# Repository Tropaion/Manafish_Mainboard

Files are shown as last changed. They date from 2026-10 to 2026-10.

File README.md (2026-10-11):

# Manafish Mainboard

The Manafish Mainboard is the main electronics board of the
[Manafish ROV](https://github.com/manafishrov). It replaces the Raspberry Pi 3B,
the USB-connected Raspberry Pi Pico and the wiring between them with one board:

- a **Raspberry Pi Compute Module 5** for the tether network, the camera and
  the vehicle firmware ([manafishrov/firmware](https://github.com/manafishrov/firmware)),
- an **RP2354A** microcontroller that drives the eight thrusters over
  bidirectional DShot ([manafishrov/mcu-firmware](https://github.com/manafishrov/mcu-firmware)),
- two camera connectors, Ethernet with PoE-capable magnetics, a magnet power
  switch input, and the on-board sensors.

> [!WARNING]
> Work in progress. The schematic and the 4-layer PCB layout are drawn, but no
> board has been built or tested. Don't manufacture from this repository yet.

## Overview
View the latest [KiCad Design](https://kicanvas.org/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).

```mermaid
flowchart LR
  tether["Tether (Ethernet)"] --> magjack["MagJack + ESD"]
  magjack -->|4 pairs| cm5["Compute Module 5"]
  magjack -.->|center taps| poe["PoE module IC5 (Ag59824, 24 V)"]
  cm5 -->|MIPI0| cam["Camera connector J5"]
  cm5 -->|MIPI1| cam2["Camera connector J11"]
  cm5 -->|"USB 2.0 (data only)"| service["USB-C service port J8"]
  cm5 -->|I2C1| sensors["BMI270, SHT45, MS5837 connector"]
  cm5 -->|"USB 2.0 (USB3-1 port)"| mcu["RP2354A"]
  cm5 -->|"GPIO24 RUN, GPIO25 BOOTSEL"| mcu
  mcu -->|GP6-GP9| escA["ESC A, 4-in-1 (AM32)"]
  mcu -->|GP18-GP21| escB["ESC B, 4-in-1 (AM32)"]
  poe --> chg["Charger IC8 (LTC4162-L)"]
  bat["Battery J6 (5S)"] <--> chg
  chg -->|VSYS| buck["5 V buck IC9 (TPSM53604)"]
  mag["Magnet switch board J12"] -->|MAG_ON| lsw
  buck -->|5 V always on| lsw["Load switch IC15 (TPS22965)"]
  lsw -->|5 V| cm5
```

## Schematic sheets

| Sheet | File | Contents | Origin |
| --- | --- | --- | --- |
| Manafish (top level) | `manafish.kicad_sch` | Sheet hierarchy, battery input J6, USB-C service port J8, magnet switch connector J12 | Original; USB-C port adapted from the CM5 IO Board |
| Raspberry Pi Compute Module 5 | `cm5.kicad_sch` | CM5 module connectors, boot and EEPROM jumper header J7 | Adapted from the CM5 IO Board |
| Camera Serial Interface | `csi.kicad_sch` | 22-pin MIPI camera connectors J5 (MIPI0) and J11 (MIPI1), 3.3 V from CM5_3.3V | Adapted from the CM5 IO Board |
| Ethernet | `ethernet.kicad_sch` | MagJack IC3 (YAGEO JXF0-1012NL, 4-pair PoE center taps), ESD protection IC1/IC2, link LEDs | Adapted from the CM5 IO Board |
| Serial Peripherals | `serial_peripherals.kicad_sch` | BMI270 IMU (SPI to the RP2354A), SHT45 humidity and temperature sensor, WSEN-PADS pressure sensor IC10, MS5837 connector | Original |
| RP2354A | `rp2354a.kicad_sch` | RP2354A with core regulator, USB, SWD connector J2, ESC connectors J3/J4 | Original, following *Hardware design with RP2350* |
| Power Management | `power_management.kicad_sch` | PoE bridges D2–D5, PoE module IC5, LTC4162-L charger IC8, 5 V buck IC9, load switch IC15 | Original |

"Adapted from the CM5 IO Board" means the sheet started from Raspberry Pi's
reference design; see [Origin and attribution](#origin-and-attribution).

## Interfaces

Compute Module 5:

| Signal | CM5 pin | Connects to |
| --- | --- | --- |
| Ethernet pairs 0–3 | 3–12 | MagJack IC3 |
| GPIO2 / GPIO3 (I2C1) | 58 / 56 | BMI270, SHT45, MS5837 connector |
| GPIO24 | 45 | RP2354A `RUN` |
| GPIO25 | 41 | RP2354A `QSPI_SS` (BOOTSEL) |
| USB3-1 D+ / D− (USB 2.0 pair) | 163 / 165 | RP2354A USB |
| MIPI0 data and clock lanes | 115–141 | Camera connector J5 |
| SDA0 / SCL0 | 82 / 80 | Camera connector J5 |
| CAM_GPIO0 / CAM_GPIO1 | 97 / 100 | Camera connector J5 |
| MIPI1 data and clock lanes | 175–196 | Camera connector J11 |
| ID_SD / ID_SC (I2C, 2.2 kΩ pull-ups R4/R5) | 36 / 35 | Camera connector J11 |
| GPIO14 / GPIO15 | 55 / 51 | Camera connector J11 pins 17 / 18 (CAM1_GPIO0 / CAM1_GPIO1) |
| USB_P / USB_N (USB 2.0) | 105 / 103 | USB-C service port J8, data only |
| nRPIBOOT, EEPROM_nWP, SYNC_OUT, USB_OTG_ID, PMIC_ENABLE, PWR_BUT | 93, 20, 18, 101, 99, 92 | Jumper header J7 |
| GPIO_VREF | 78 | CM5_3.3V (3.3 V GPIO levels) |
| +5 V input | 77–87 | Power management, through load switch IC15 |
| CM5_3.3V output | 84 / 86 | RP2354A and sensors |

RP2354A (QFN-60):

| Signal | RP2354A pin | Connects to |
| --- | --- | --- |
| GP6–GP9 | 9, 10, 12, 13 | ESC A connector J3 |
| GP18–GP21 | 29, 31, 32, 33 | ESC B connector J4 |
| USB_DP / USB_DM | 52 / 51 | CM5 USB3-1, 27 Ω in series |
| RUN | 26 | CM5 GPIO24 |
| QSPI_SS | 60 | CM5 GPIO25 |
| SWCLK / SWDIO | 24 / 25 | Debug connector J2 |
| XIN / XOUT | 21 / 22 | 12 MHz crystal Y1 (ABM8-272-T3) |

I2C devices on the CM5's I2C1 bus:

| Device | Address | Notes |
| --- | --- | --- |
| BMI270 IMU | `0x68` | `0x69` if SDO is pulled to VDDIO |
| SHT45-AD1F (with PTFE membrane) | `0x44` | |
| MS5837-30BA pressure sensor (external module) | `0x76` | Fixed address |

## Repository layout

```text
hardware/
├── manafish.kicad_pro      KiCad project
├── *.kicad_sch             schematic sheets
├── manafish.kicad_pcb      PCB, 4 layers
├── manafish.kicad_dru      custom DRC rules for the PoE isolation barriers
├── sym-lib-table           project symbol libraries
├── fp-lib-table            project footprint libraries
└── custom_components/
    ├── symbols/            CM5IO, BMI270, SHT45, ABM8-272-T3, Silvertel, V6K100DUHM3, FDMC8327L, LTC4162, YAGEO symbols
    ├── footprints/         CM5IO, BMI270, SHT45, ABM8-272-T3, RP2350_Minimal, Silvertel, V6K100DUHM3, FDMC86139P, LTC4162, YAGEO footprints
    └── 3d/                 STEP models
```

## PCB

`manafish.kicad_pcb` is a 70 × 100 mm, 4-layer board. It sits centred on the
axis of a tube with a 74 mm inner diameter, so a part at lateral distance *d*
from the axis may stand at most √(37² − *d*²) − 0.8 mm above the board surface.
Every part fits, checked against the 3D models. The tightest are the USB-C port
J8 (1.8 mm to the tube wall) and the SWD connector J2 (2.3 mm).

### Stackup

JLCPCB JLC04161H-7628, 1.6 mm, ENIG finish:

| Layer | Thickness | Use |
| --- | --- | --- |
| F.Cu | 35 µm | Parts, signals, GND and power pours |
| Prepreg 7628 | 0.21 mm, εr 4.4 | |
| In1.Cu | 15 µm | Solid GND reference, no tracks |
| Core | 1.065 mm, εr 4.6 | |
| In2.Cu | 15 µm | GND, power pours (VSYS, +5 V, 3V3), signals |
| Prepreg 7628 | 0.21 mm, εr 4.4 | |
| B.Cu | 35 µm | PoE module IC5, PoE input, signals, GND and 24 V pours |

Order the board with impedance control:

| Net class | Nets | Width / gap | Target |
| --- | --- | --- | --- |
| `DP100` | Ethernet `TRD*`, camera `DPHY0_*` and `DPHY1_*` | 0.21 / 0.19 mm on F.Cu and B.Cu | 100 Ω differential |
| `USB90` | `USB2_*`, RP2354A `USB_D*` | 0.24 / 0.15 mm on F.Cu | 90 Ω differential |

Inside the CM5 connector pin fields the pairs neck down to 0.127 mm for at most
1.6 mm. Pours keep 0.3 mm from the pairs everywhere.

### PoE isolation

The PoE input side (the `Primary` net class: center taps, bridges, IC5 input,
TYP outputs) is isolated from the rest of the board. `manafish.kicad_dru`
enforces:

- 2.0 mm from primary copper to any other net, on every layer and from every
  hole. The only exception is between the pads of each Y-capacitor
  (C21, C24).
- A 3.0 mm warning tier, the Silvertel guideline. 21 warnings remain, all
  between 2.0 and 3.0 mm:
  - the MagJack's own center-tap pads to its shield pins (2.14 mm) and the VC3
    track next to the shield (2.02 mm);
  - the Y-capacitors' own pads (2.7 mm) and C21's GND pad to the ferrite beads
    (2.26 mm);
  - the RP2354A decoupling GND vias next to the ferrite-bead column (2.38 mm);
  - R23 next to IC5's VIN+ pad (2.8 mm).
- Under IC5's primary half (`PRI_ISLAND_U5`), no vias of other nets and no
  other copper on B.Cu or In2. The module's isolation barrier strip stays
  empty on B.Cu and In2.

The inner layers are voided 2 mm around primary copper on the next outer layer
(In2 under primary B.Cu, In1 under primary F.Cu), and In1 stays clear of the
front edge where the VC1 track runs on In2. Only IC5, the optocouplers IC6/IC7 and
the Y-capacitors C21/C24 cross the barrier.

Connector A of the CM5 lies inside the island, so 16 of its GND pins have no
via to the GND planes. They connect through the CM5's own ground: the footprint
`Module1` declares all its GND pads as one jumper pad group.

### Assembly

- IC5 (Ag59824-LPB) is on the bottom and must never pass through reflow hanging
  upside down. Reflow the top side first, then the bottom side with IC5 upright,
  or fit IC5 afterwards with hot air. Glue L2 (1.0–1.6 g) and IC9 before the
  second pass.
- IC5 reflow profile: peak 230–245 °C, 30–90 s above 217 °C, soak 150–180 °C for
  30–90 s, ramp up at most 3 °C/s and down at most 6 °C/s. No wave solder on the
  IC5 side.
- Solder the through-hole parts IC3, J6, J7 and C20 by hand after both reflow
  passes.
- Fit the CM5 with M2.5 screws from below (head at most 4.5 mm across) and the
  nuts on the CM5 side. A nut under the board would hit C20.

The same notes are on the board's User.Comments layer, which isn't part of the
Gerbers: copy them into the order remarks for the assembler.

### Testing the isolation

Use the 1500 V 10/700 µs impulse test only, at normal air pressure. Don't run
a 1500 Vrms or 2250 Vdc hipot: the Ag59824 is rated only for the impulse
test, and 2250 V exceeds the Y-capacitors' 2 kV rating. Afterwards the primary
side must measure at least 2 MΩ to GND at 500 Vdc.

## Flashing the Compute Module

The USB-C port J8 carries data only. Its VBUS isn't connected, so the board
needs its normal supply while you flash it.

1. Power the board.
2. Fit a jumper on J7 pins 1–2 (`nRPIBOOT`).
3. Connect J8 to a computer and run
   [`rpiboot`](https://github.com/raspberrypi/usbboot)
   `-d mass-storage-gadget64`. The eMMC appears as a USB drive.
4. Write the image, then remove the jumper.

Set `PSU_MAX_CURRENT=5000` in the bootloader EEPROM configuration. The CM5
isn't powered over USB-C, so it can't detect the supply's capability itself.

Jumper header J7:

| Pins | Signal | Fitted means |
| --- | --- | --- |
| 1–2 | `nRPIBOOT` | Boot from USB, for flashing |
| 3–4 | `EEPROM_nWP` | Bootloader EEPROM write-protected; blocks EEPROM updates |
| 5–6 | `SYNC_OUT` | Ethernet timing output; never fit a jumper |
| 9–10 | `USB_OTG_ID` | USB 2.0 port in host mode; leave open for flashing |
| 11–12 | `PMIC_ENABLE` | CM5 switched off |
| 13–14 | `PWR_BUT` | For a push button: short press shuts down or wakes, holding over 5 s forces power-off |

## Opening the project

1. Install [KiCad](https://www.kicad.org/) 10.0 or newer. The files are saved
   in the KiCad 10 format and won't open in older versions.
2. Open `hardware/manafish.kicad_pro`. The project libraries in
   `custom_components/` are registered in `sym-lib-table` and `fp-lib-table`;
   everything else comes from KiCad's standard libraries.

Datasheets aren't stored in the repository. Use the links below.

## Datasheets

- [Raspberry Pi Compute Module 5 datasheet](https://datasheets.raspberrypi.com/cm5/cm5-datasheet.pdf)
- [Compute Module 5 IO Board datasheet](https://datasheets.raspberrypi.com/cm5/cm5io-datasheet.pdf)
- [RP2350 datasheet](https://datasheets.raspberrypi.com/rp2350/rp2350-datasheet.pdf)
- [Hardware design with RP2350](https://datasheets.raspberrypi.com/rp2350/hardware-design-with-rp2350.pdf)
- [RP2350 product brief](https://datasheets.raspberrypi.com/rp2350/rp2350-product-brief.pdf)
- [Bosch BMI270 datasheet](https://www.bosch-sensortec.com/media/boschsensortec/downloads/datasheets/bst-bmi270-ds000.pdf)
- [Sensirion SHT45 product page and datasheet](https://sensirion.com/products/catalog/SHT45)
- [Silvertel Ag5700-LPB (Ag5724-LPB) PoE module datasheet](https://silvertel.com/images/datasheets/Ag5700LPB-datasheet-minature%20IEEE802_3At%2024W%20power-over-ethernet%20module.pdf)
- [Silvertel Ag59800 (Ag59824-LPB) PoE++ module datasheet](https://silvertel.com/images/datasheets/Ag59800-LPB%20-datasheet-high%20efficiency%20SMT%20IEEE802_3BT%20100W%20power-over-ethernet%20module.pdf)
- [Vishay V6K100DU dual Schottky diode datasheet](https://www.vishay.com/docs/87418/v6k100du.pdf)
- [Analog Devices LTC4162-L battery charger datasheet](https://www.analog.com/media/en/technical-documentation/data-sheets/LTC4162-L.pdf)
- [YAGEO (Pulse) JXF0-xx12NL MagJack datasheet J520](https://www.yageogroup.com/content/datasheet/asset/file/DATASHEET_J520)

## Related repositories

- [manafishrov/firmware](https://github.com/manafishrov/firmware): vehicle
  firmware running on the Compute Module
- [manafishrov/mcu-firmware](https://github.com/manafishrov/mcu-firmware):
  thruster firmware running on the RP2354A (Pico 2 build)
- [manafishrov/esc-firmware](https://github.com/manafishrov/esc-firmware):
  AM32 firmware for the ESCs

## Origin and attribution

This board builds on the **Raspberry Pi Compute Module 5 IO Board (CM5IO)**
reference design by Raspberry Pi Ltd.

- **Source:** *CM5 IO Board, revision 2, KiCad files* (Raspberry Pi document
  RP-008099-DD-1), downloaded from the
  [Raspberry Pi Product Information Portal](https://pip.raspberrypi.com/categories/1098-design-files).
  The original files carry the notice "Copyright © 2024 Raspberry Pi Ltd."
- **Copied unchanged:** the symbol library
  `custom_components/symbols/CM5IO.kicad_sym`, all footprints in
  `custom_components/footprints/CM5IO.pretty/`, and eight 3D models in
  `custom_components/3d/`.
- **Adapted:** the circuits in `cm5.kicad_sch`, `csi.kicad_sch` and
  `ethernet.kicad_sch`, including the boot and EEPROM jumper header J7, and
  the USB-C service port J8 in `manafish.kicad_sch`.
- **Terms:** the CM5 IO Board datasheet says the design files "can be used in
  your own reference designs", and Raspberry Pi grants permission to use its
  resources "solely in conjunction with the Raspberry Pi products". These files
  and the parts derived from them remain © Raspberry Pi Ltd under those terms.
  They are **not** covered by this repository's license.

The RP2354A circuit follows Raspberry Pi's
[*Hardware design with RP2350*](https://datasheets.raspberrypi.com/rp2350/hardware-design-with-rp2350.pdf)
(RP-008280-DS). The footprints for the core regulator inductor L1 and the SWD
connector J2 come from Raspberry Pi's RP2350A minimal design, published under
the MIT license.

Raspberry Pi is a trademark of Raspberry Pi Ltd. This project is not affiliated
with or endorsed by Raspberry Pi Ltd.

[NOTICE.md](NOTICE.md) lists every third-party file and its terms.

## License

The original work in this repository is licensed under the GNU Affero General
Public License v3.0 or later; see [LICENSE](LICENSE). Third-party files keep
their own terms, listed in [NOTICE.md](NOTICE.md).

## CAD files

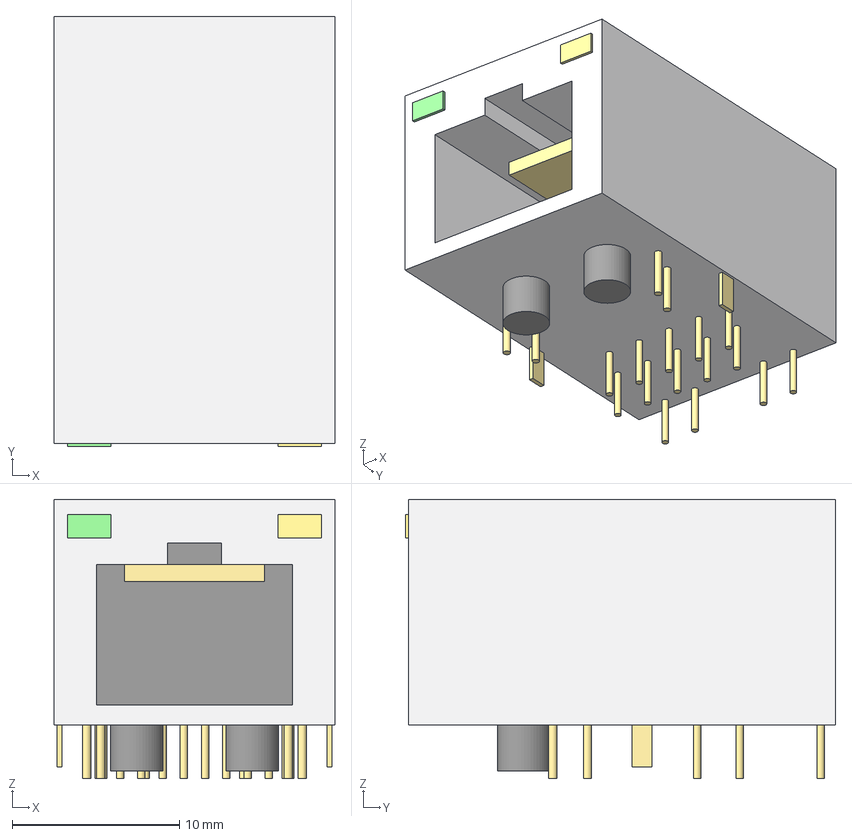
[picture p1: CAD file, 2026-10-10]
hardware/custom_components/3d/JXF0-1012NL.step
16.8 x 25.7 x 16.7 mm
shield
socket
contacts
led_green
led_yellow
pin0
pin1
pin2
pin3
pin4
pin5
pin6
pin7
pin8
pin9
pin10
pin11
pin12
pin13
pin14
pin15
pin16
pin17
pin18
pin19
peg0
peg1

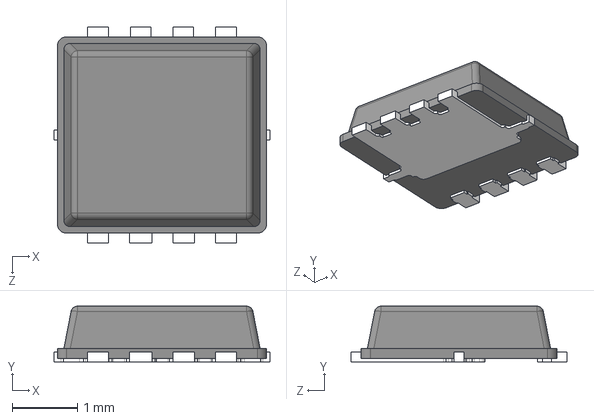
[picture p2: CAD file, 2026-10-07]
hardware/custom_components/3d/FDMC8327L.stp
3.30 x 0.85 x 3.30 mm

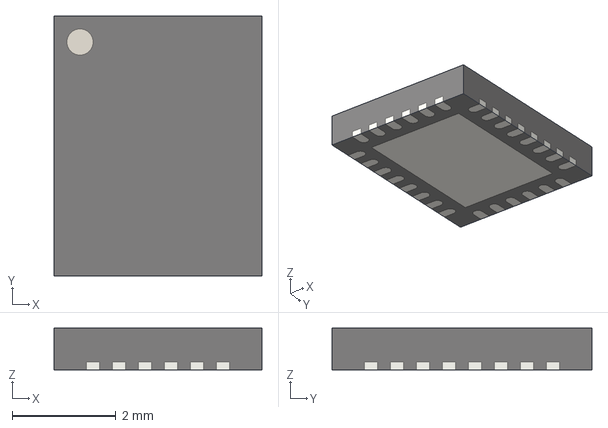
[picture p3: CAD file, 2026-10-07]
hardware/custom_components/3d/QFN-28-1EP_4x5mm_P0.5mm_EP2.65x3.65mm.step
4.00 x 5.00 x 0.8 mm

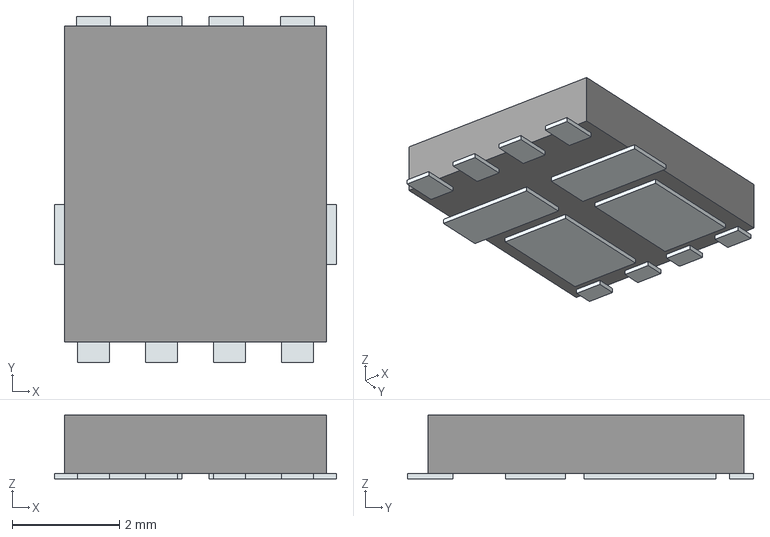
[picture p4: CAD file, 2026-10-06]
hardware/custom_components/3d/V6K100DUHM3_H.stp
5.27 x 6.46 x 1.19 mm
Pins

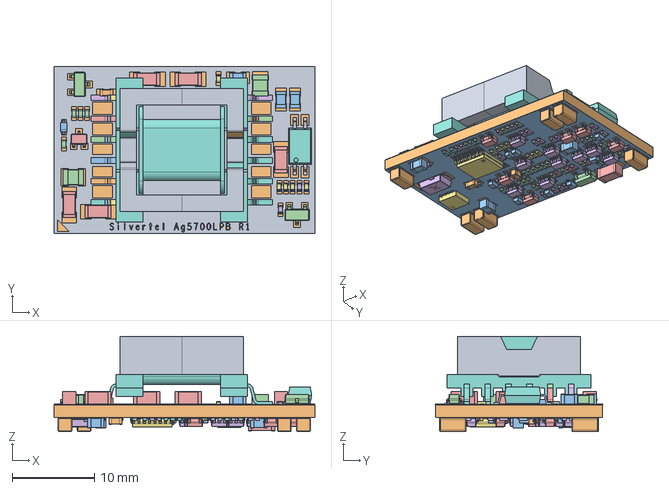
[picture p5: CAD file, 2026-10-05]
hardware/custom_components/3d/AG5700.step
31.7 x 20.3 x 11.6 mm

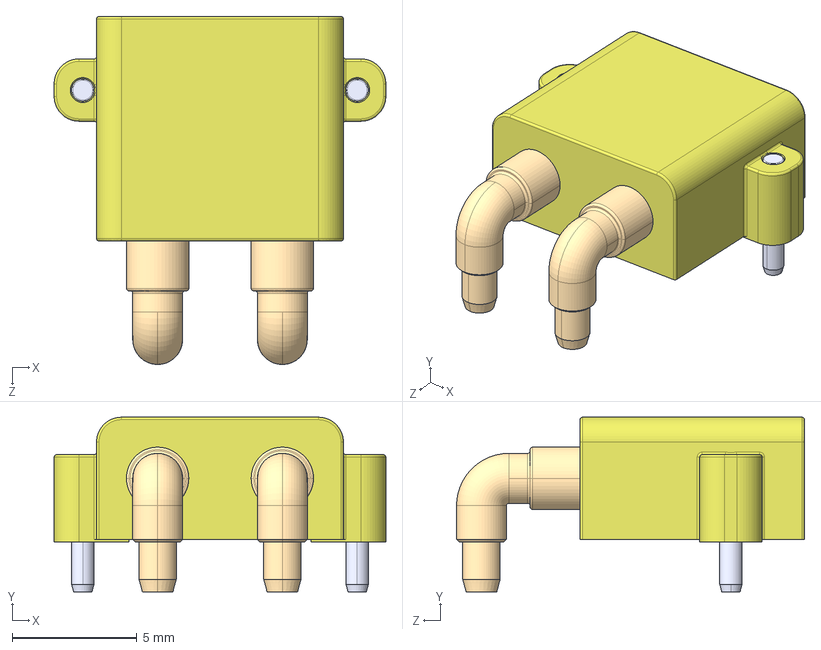
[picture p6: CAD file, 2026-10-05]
hardware/custom_components/3d/AMASS_XT30PW-M.step
13.3 x 7.00 x 14.0 mm

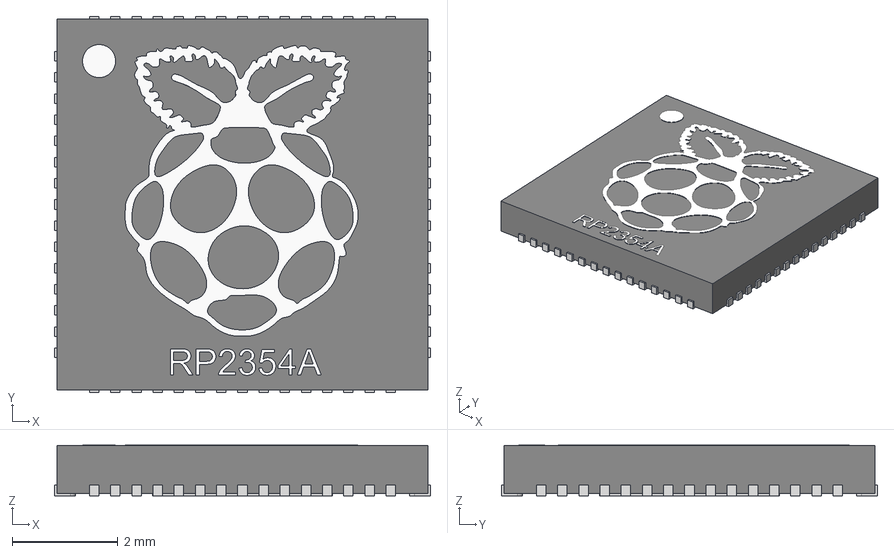
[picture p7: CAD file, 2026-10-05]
hardware/custom_components/3d/RP2354A.stp
7.10 x 7.10 x 0.96 mm

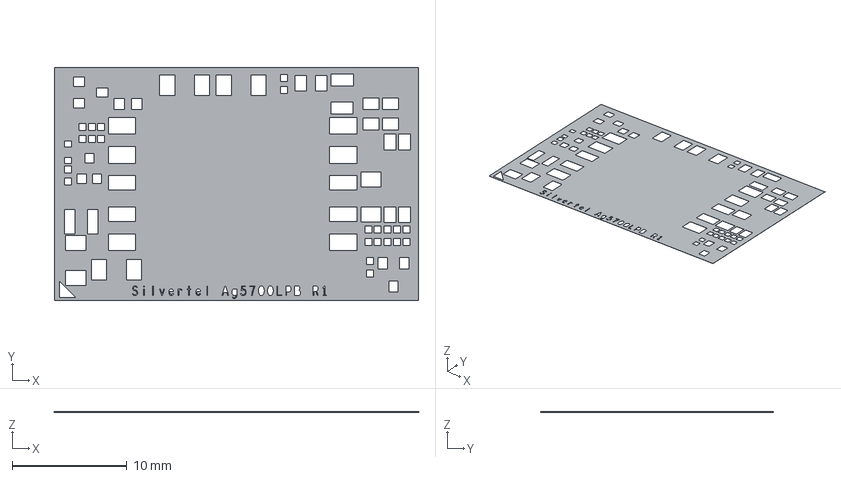
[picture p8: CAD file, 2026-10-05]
hardware/custom_components/3d/Ag5700_detailed.step
31.7 x 20.3 x 0.0127 mm

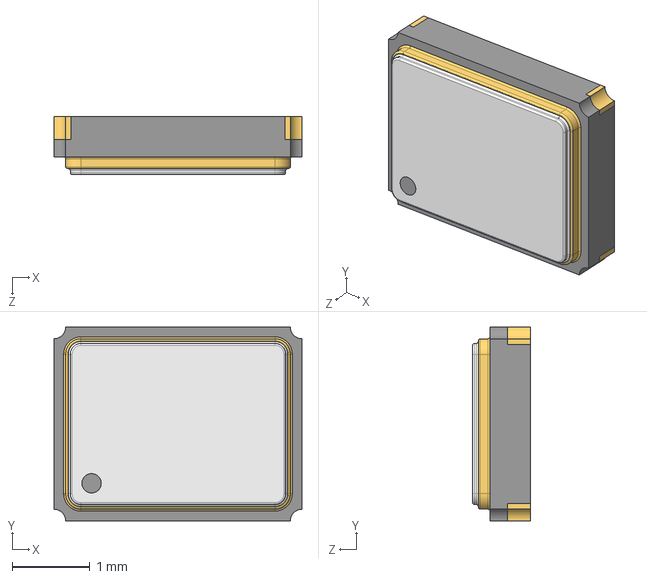
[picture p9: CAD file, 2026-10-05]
hardware/custom_components/3d/ABM8-272-T3.stp
3.20 x 2.50 x 0.75 mm

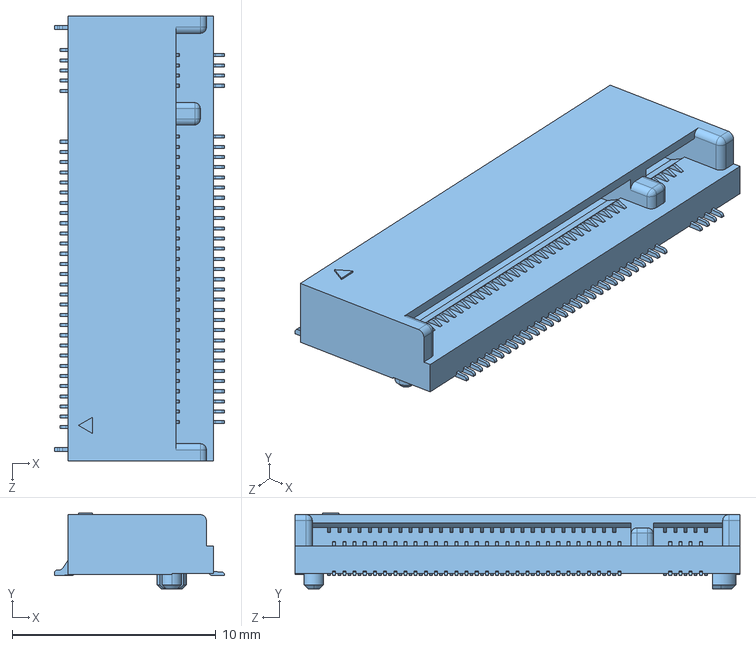
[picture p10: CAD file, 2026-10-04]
hardware/custom_components/3d/MTSSD03-67MSW337.STEP
8.37 x 3.73 x 21.9 mm

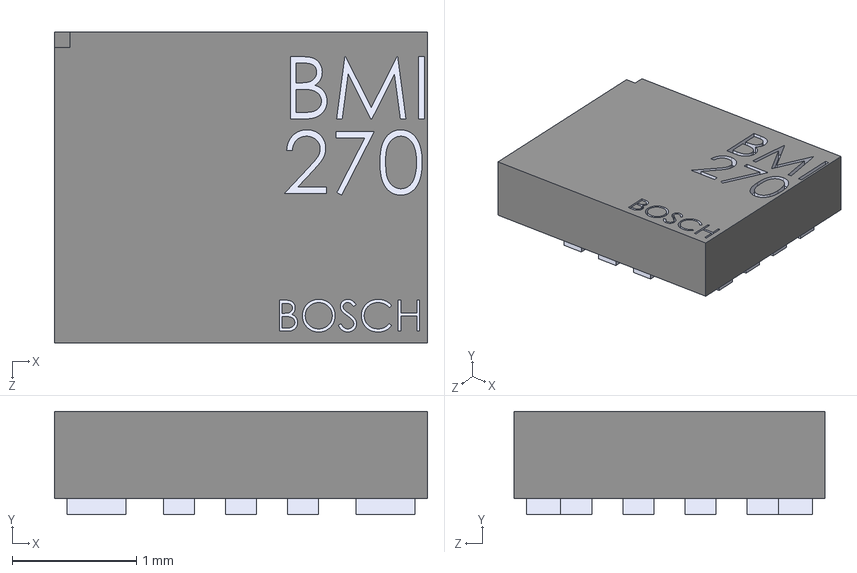
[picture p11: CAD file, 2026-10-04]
hardware/custom_components/3d/BMI270.stp
3.00 x 0.83 x 2.50 mm

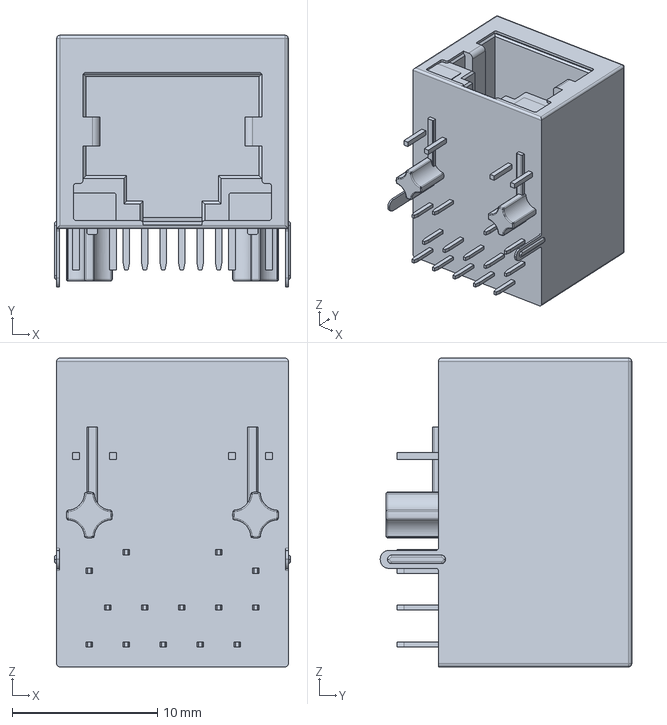
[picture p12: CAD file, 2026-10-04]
hardware/custom_components/3d/TRJG0926HENL .stp
16.2 x 17.3 x 21.2 mm

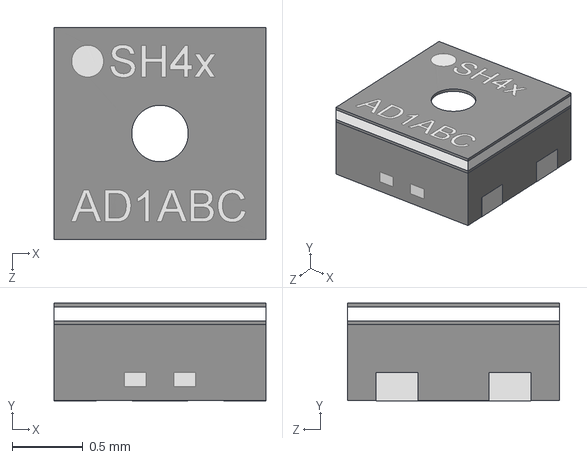
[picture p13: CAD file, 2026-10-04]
hardware/custom_components/3d/SHT45-AD1F-R2.stp
1.50 x 0.691 x 1.50 mm

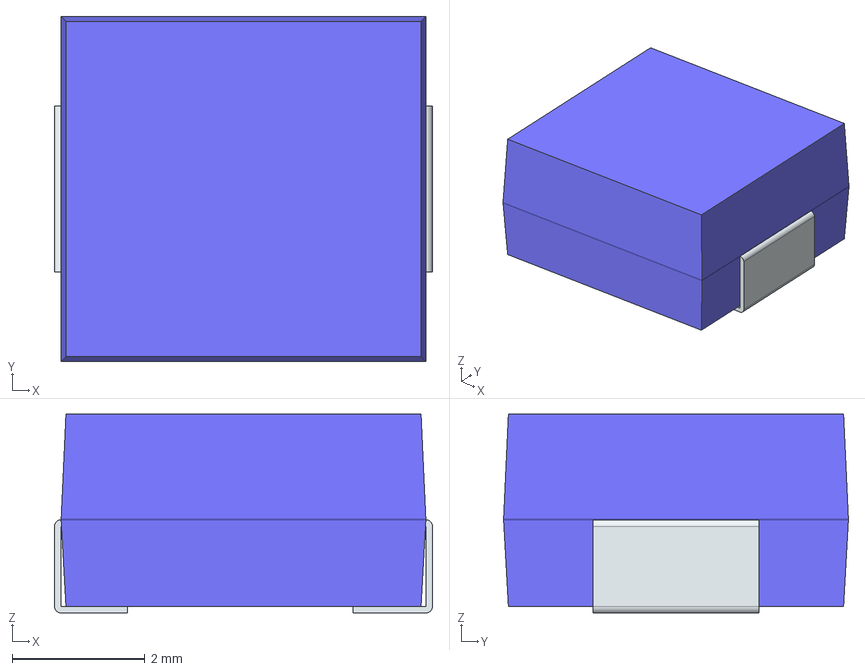
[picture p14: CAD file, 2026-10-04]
hardware/custom_components/3d/SRP5030CC.stp
5.70 x 5.20 x 3.00 mm
FilletPin1
FilletPin2

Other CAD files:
hardware/custom_components/3d/FH12-22S-0.5SH.stp
hardware/custom_components/3d/BM04B-SRSS-TB.STEP
hardware/custom_components/3d/CM5R5.step
hardware/custom_components/3d/AG59800-LPB.step
hardware/custom_components/3d/10164227-1001a1rlf.stp
hardware/custom_components/3d/471511051.stp

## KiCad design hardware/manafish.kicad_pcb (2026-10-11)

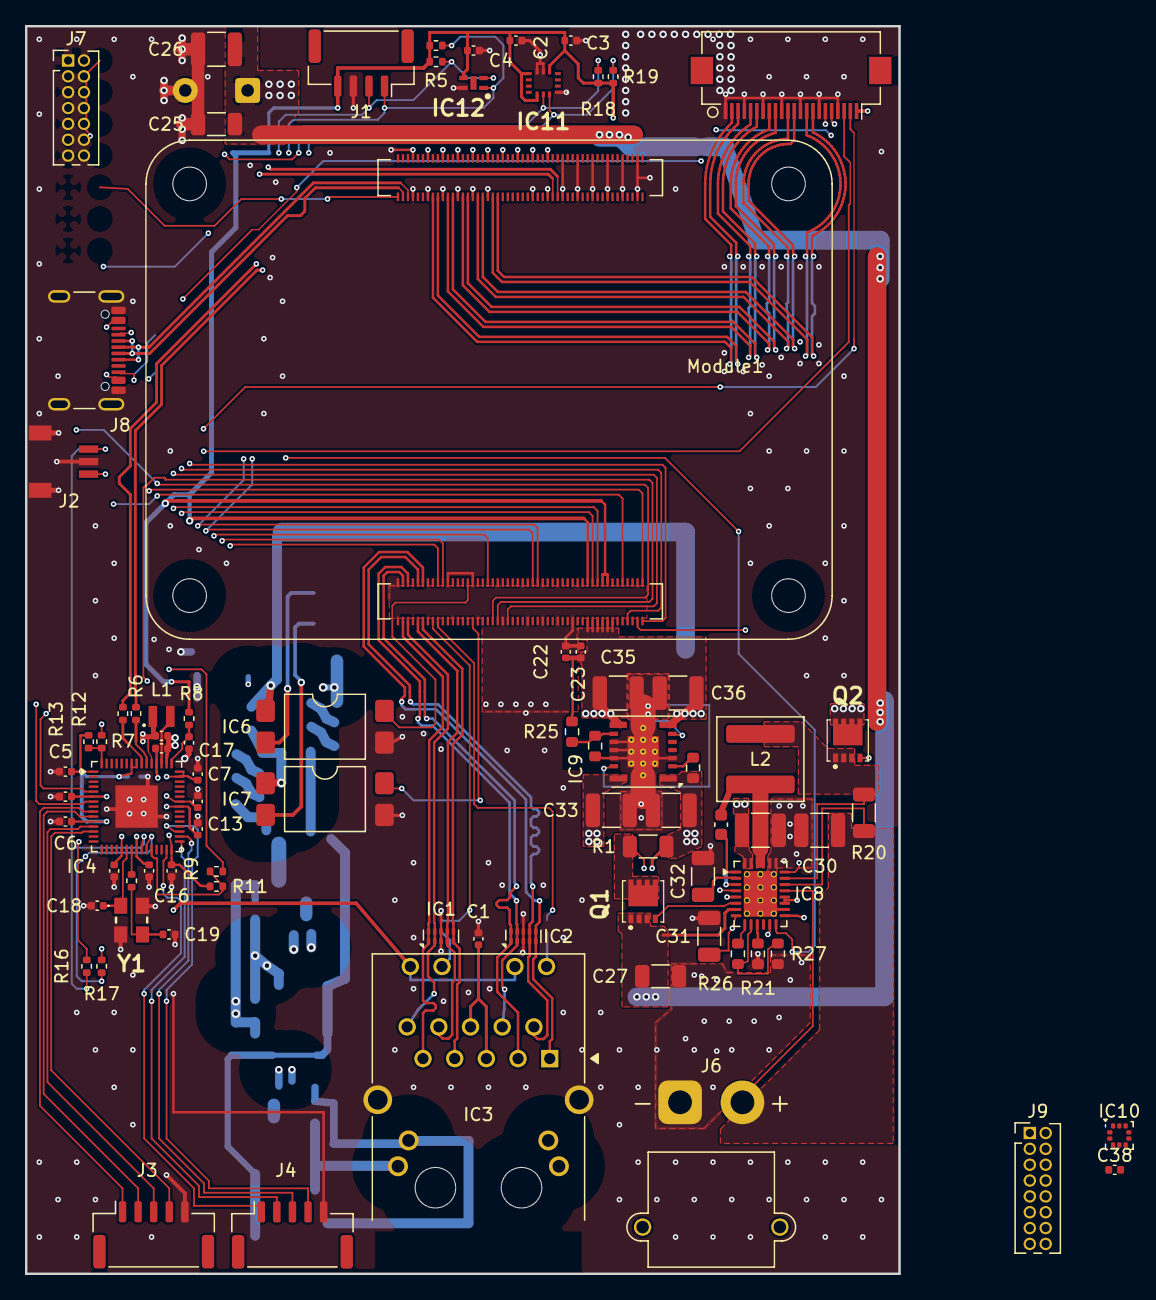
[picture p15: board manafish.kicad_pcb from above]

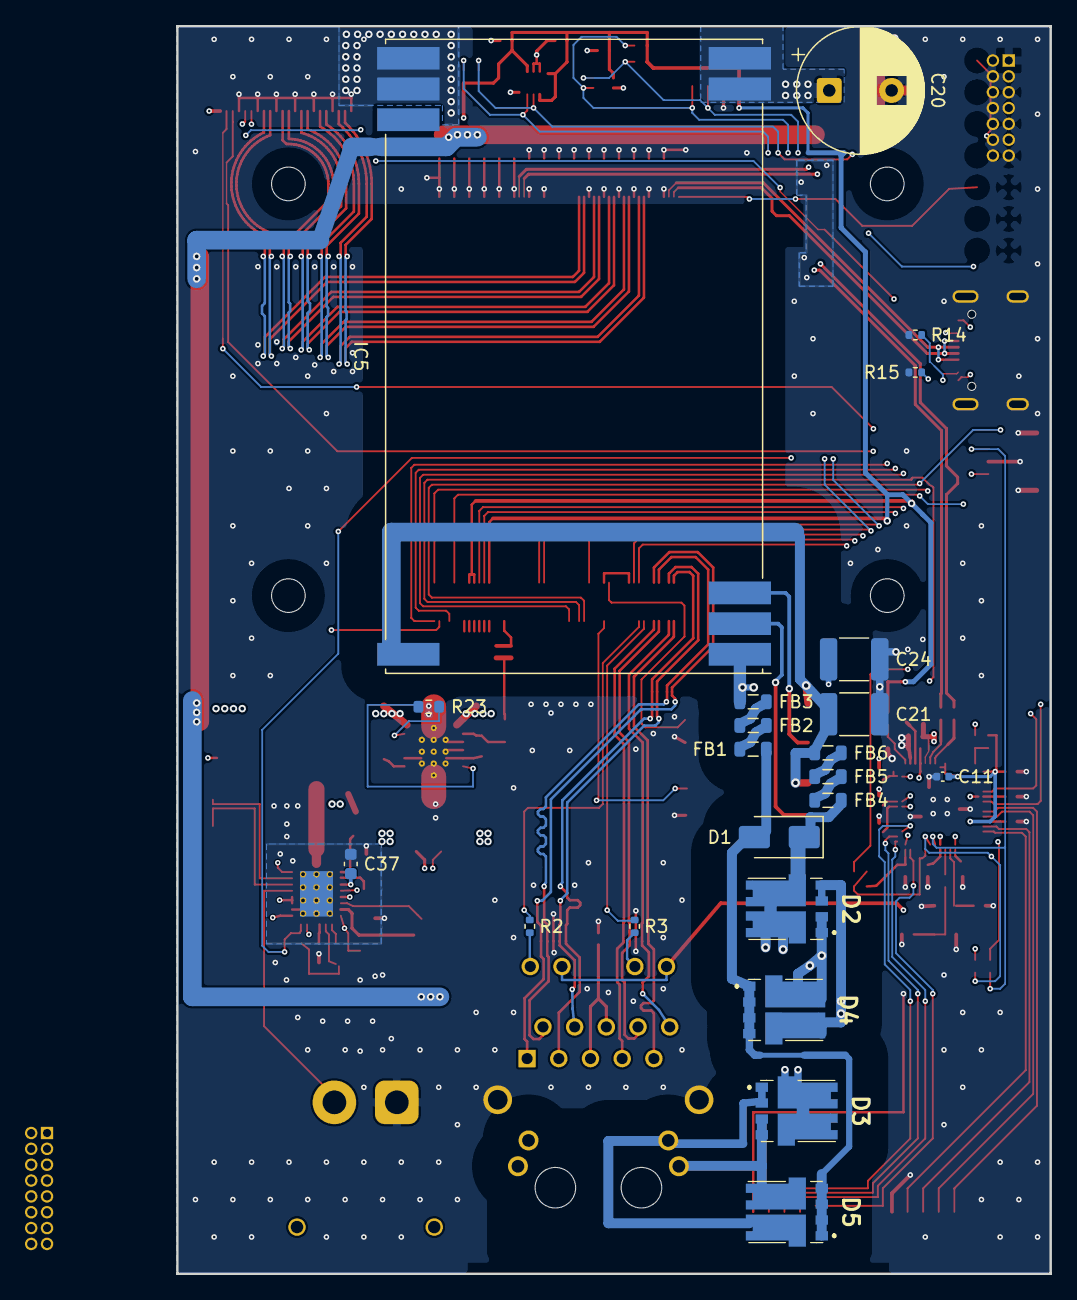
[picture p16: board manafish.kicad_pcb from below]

Board: 4 copper layers, 70.0 x 100.0 mm, 103 parts (22 on the bottom side), 122 nets.

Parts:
C1, C2, C3, C4, C5, C6, C7, C8, C9, C10, C11, C12, C13, C16, C22, C23, C38: 100n; C_0402_1005Metric
C14, C15, C17: 4.7uF; C_0402_1005Metric
C18, C19: 15pF; C_0402_1005Metric
C20: 470uF 35V; CP_Radial_D10.0mm_P5.00mm
C21, C24: 4.7nF 2kV; C_1812_4532Metric
C25, C27: 100nF 50V; C_1206_3216Metric
C26, C28, C30, C33, C34: 10uF 50V; C_1210_3225Metric
C29: 22nF 50V; C_0603_1608Metric
C31: 1uF 50V; C_1206_3216Metric
C32: 4.7uF 50V; C_1206_3216Metric
C35, C36: 47uF 10V; C_1210_3225Metric
C37: 100nF 50V; C_0603_1608Metric
D1: SMAJ58A; D_SMA
D2, D3, D4, D5: V6K100DUHM3_H; V6K100DUHM3H
FB1, FB2, FB3, FB4, FB5, FB6: 1kR 1.5A; L_0805_2012Metric
IC1, IC2: TPD4EUSB30; USON-10_2.5x1.0mm_P0.5mm
IC3: JXF0-1012NL; YAGEO_JXF0-1012NL
IC4: RP2354A; QFN-60-1EP_7x7mm_P0.4mm_EP3.4x3.4mm
IC5: Ag59824-LPB; Silvertel_Ag59800-LPB
IC6, IC7: LTV-817S; SMDIP-4_W9.53mm_Clearance8mm
IC8: LTC4162-LAD; QFN-28-1EP_4x5mm_P0.5mm_EP2.65x3.65mm_ThermalVias0.3mm
IC9: TPSM53603RDA; Texas_B3QFN-14-1EP_5x5.5mm_P0.65mm_ThermalVia
IC10: WSEN-PADS_2511020213301; ST_HLGA-10_2x2mm_P0.5mm_LayoutBorder3x2y
IC11: BMI270
IC12: SHT45-AD1F-R2; SON80P150X150X59-5N
J1: Conn_01x04_Pin; JST_GH_SM04B-GHS-TB_1x04-1MP_P1.25mm_Horizontal
J2: SM03B-SRSS-TB; jst_sm03b-srss-tb-lf--sn-
J3: AM32_1; JST_GH_SM05B-GHS-TB_1x05-1MP_P1.25mm_Horizontal
J4: AM32_2; JST_GH_SM05B-GHS-TB_1x05-1MP_P1.25mm_Horizontal
J5: Conn_01x22_Female; Hirose_FH12-22S-0.5SH_1x22-1MP_P0.50mm_Horizontal
J6: Battery; AMASS_XT30PW-M_1x02_P2.50mm_Horizontal
J7: Conn_02x07_Odd_Even; PinHeader_2x07_P1.27mm_Vertical
J8: USB_C_Receptacle_USB2.0_14P; USB_C_Receptacle_GCT_USB4105-xx-A_16P_TopMnt_Horizontal
J9: Conn_02x08_Odd_Even; PinHeader_2x08_P1.27mm_Vertical
L1: 3.3uH 2.1A; abracon_aota-b201610s3r3-101-t
L2: 6.8uH; L_Coilcraft_XAL6060-XXX
Module1: ComputeModule5-CM5; Raspberry-Pi-5-Compute-Module
Q1, Q2: FDMC8327L; FDMC86139P
R1: 16mR; R_1206_3216Metric
R2, R3: 470R; R_0402_1005Metric
R4, R5, R11, R18, R19: 4.7kR; R_0402_1005Metric
R6, R7: 27R; R_0402_1005Metric
R8, R16, R17: 33R; R_0402_1005Metric
R9: 330R; R_0402_1005Metric
R10, R12: 1kR; R_0402_1005Metric
R13: 10kR; R_0402_1005Metric
R14, R15: 5.1kR; R_0402_1005Metric
R20: 10mR; R_1206_3216Metric
R21: 63.4kR; R_0603_1608Metric
R22, R23: 100kR; R_0603_1608Metric
R24: 2.49kR; R_0603_1608Metric
R25, R26, R27: 10kR; R_0603_1608Metric
Y1: ABM8-272-T3; ABM8272T3

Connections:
/Camera Serial Interface/CAM_GPIO0: J5.17, Module1.97 (CAM_GPIO0)
/Camera Serial Interface/CAM_GPIO1: J5.18, Module1.100 (CAM_GPIO1)
/Camera Serial Interface/DPHY0_C_N: J5.8, Module1.127 (MIPI0_C_N)
/Camera Serial Interface/DPHY0_C_P: J5.9, Module1.129 (MIPI0_C_P)
/Camera Serial Interface/DPHY0_D0_N: J5.2, Module1.115 (MIPI0_D0_N)
/Camera Serial Interface/DPHY0_D0_P: J5.3, Module1.117 (MIPI0_D0_P)
/Camera Serial Interface/DPHY0_D1_N: J5.5, Module1.121 (MIPI0_D1_N)
/Camera Serial Interface/DPHY0_D1_P: J5.6, Module1.123 (MIPI0_D1_P)
/Camera Serial Interface/DPHY0_D2_N: J5.11, Module1.133 (MIPI0_D2_N)
/Camera Serial Interface/DPHY0_D2_P: J5.12, Module1.135 (MIPI0_D2_P)
/Camera Serial Interface/DPHY0_D3_N: J5.14, Module1.139 (MIPI0_D3_N)
/Camera Serial Interface/DPHY0_D3_P: J5.15, Module1.141 (MIPI0_D3_P)
/Camera Serial Interface/SCL0: J5.20, Module1.80 (SCL0)
/Camera Serial Interface/SDA0: J5.21, Module1.82 (SDA0)
/Ethernet/ETH_LEDG: Module1.17 (Ethernet_nLED2(3.3v)), R2.2
/Ethernet/ETH_LEDY: Module1.15 (Ethernet_nLED3(3.3v)), R3.2
/Ethernet/TRD0_N: IC2.4 (D2+), IC2.7, IC3.2 (MD1-), Module1.10 (Ethernet_Pair0_N)
/Ethernet/TRD0_P: IC2.5 (D2-), IC2.6, IC3.1 (MD1+), Module1.12 (Ethernet_Pair0_P)
/Ethernet/TRD1_N: IC2.2 (D1-), IC2.9, IC3.4 (MD2-), Module1.6 (Ethernet_Pair1_N)
/Ethernet/TRD1_P: IC2.1 (D1+), IC2.10, IC3.3 (MD2+), Module1.4 (Ethernet_Pair1_P)
/Ethernet/TRD2_N: IC1.4 (D2+), IC1.7, IC3.8 (MD3-), Module1.9 (Ethernet_Pair2_N)
/Ethernet/TRD2_P: IC1.5 (D2-), IC1.6, IC3.7 (MD3+), Module1.11 (Ethernet_Pair2_P)
/Ethernet/TRD3_N: IC1.2 (D1-), IC1.9, IC3.10 (MD4-), Module1.5 (Ethernet_Pair3_N)
/Ethernet/TRD3_P: IC1.1 (D1+), IC1.10, IC3.9 (MD4+), Module1.3 (Ethernet_Pair3_P)
/Ethernet/VC1: D2.3, D2.4, D4.5, D4.6, IC3.15 (VDC1+)
/Ethernet/VC2: D3.3, D3.4, D5.5, D5.6, IC3.17 (VDC2+)
/Ethernet/VC3: D3.1, D3.2, D5.7, D5.8, IC3.18 (VDC2-)
/Ethernet/VC4: D2.1, D2.2, D4.7, D4.8, IC3.16 (VDC1-)
/I2C Peripherals/I2C0_SCL: IC4.5 (GPIO3), IC11.13 (SCX), R18.2
/I2C Peripherals/I2C0_SDA: IC4.7 (GPIO4), IC11.14 (SDX), R19.2
/I2C Peripherals/I2C1_SCL: IC8.13 (SCL), IC10.2 (SCL), IC12.2 (SCL), J1.2, Module1.56 (GPIO3), R4.2
/I2C Peripherals/I2C1_SDA: IC8.14 (SDA), IC10.4 (SDA), IC12.1 (SDA), J1.1, Module1.58 (GPIO2), R5.2
/I2C Peripherals/INT_DRDY: IC10.7 (INT_DRDY), Module1.24 (GPIO26)
/Power Management/24V: C20.1, C25.1, C26.1, C27.1, IC5.4 (VOUT+), IC5.5 (VOUT+), IC8.7 (VIN), Q1.1 (S_1), Q1.2 (S_2), Q1.3 (S_3)
/Power Management/+5V: C22.1, C23.1, C35.1, C36.1, IC9.7 (VOUT), IC9.8 (VOUT), Module1.77 (+5v_(Input)), Module1.79 (+5v_(Input)), Module1.81 (+5v_(Input)), Module1.83 (+5v_(Input)), Module1.85 (+5v_(Input)), Module1.87 (+5v_(Input)), R25.1
/Power Management/BAT+: C30.1, IC8.19 (BATSENS+), IC8.20 (CSN), J6.2, R20.2
/Power Management/POE_TYP2_DET: IC6.4, Module1.30 (GPIO6)
/Power Management/POE_TYP3_DET: IC7.4, Module1.31 (GPIO12)
/Power Management/VSYS: C28.1, C33.1, C34.1, C37.1, IC8.3 (VOUTA), IC8.4 (CLN), IC8.27 (VOUT), IC8.28 (VOUT), IC9.1 (VIN), IC9.14 (VIN), Q2.5 (D_1), Q2.6 (D_2), Q2.7 (D_3), Q2.8 (D_4), R1.2, R22.1
/RP2354A/BOOTSEL: Module1.41 (GPIO25), R12.2
/RP2354A/RP2354_SWCLK: Module1.38 (GPIO11), R16.2
/RP2354A/RP2354_SWDIO: Module1.39 (GPIO8), R17.2
/RP2354A/RUN: Module1.45 (GPIO24), R9.2
/RP2354A/USB_D+: Module1.163 (USB3-1-D_P), R7.2
/RP2354A/USB_D-: Module1.165 (USB3-1-D_N), R6.2
/RP2354A/VREG_FB: C12.1, C13.1, C14.1, C16.1, IC4.6 (DVDD), IC4.23 (DVDD), IC4.39 (DVDD), IC4.50 (VREG_FB), L1.1
/RP2354A/VREG_LX: IC4.48 (VREG_LX), L1.2
/RP2354A/VREG_VIN: C2.1, C3.1, C4.1, C5.1, C6.1, C7.1, C8.1, C9.1, C10.1, C11.1, C15.1, C38.1, IC3.11 (LEDG_A), IC3.13 (LEDY_A), IC4.1 (IOVDD), IC4.11 (IOVDD), IC4.20 (IOVDD), IC4.30 (IOVDD), IC4.38 (IOVDD), IC4.44 (ADC_AVDD), IC4.45 (IOVDD), IC4.49 (VREG_VIN), IC4.53 (USB_OTP_VDD), IC4.54 (QSPI_IOVDD), IC8.15 (DVCC), IC10.1 (Vdd_IO), IC10.10 (VDD), IC11.5 (VDDIO), IC11.8 (VDD), IC11.12 (CSB), IC12.3 (VDD), J1.4, J5.22, Module1.78 (GPIO_VREF(1.8v/3.3v_Input)), Module1.84 (+3.3v_(Output)), Module1.86 (+3.3v_(Output)), R4.1, R5.1, R8.1, R11.1, R13.1, R18.1, R19.1
/RP2354A/XIN: C18.1, IC4.21 (XIN), Y1.1 (CRYSTAL_1)
/RP2354A/XOUT: IC4.22 (XOUT), R10.2
/Rasperry Pi Compute Module 5/EEPROM_nWP: J7.4, Module1.20 (EEPROM_nWP)
/Rasperry Pi Compute Module 5/GPIO4: J9.16, Module1.54 (GPIO4)
/Rasperry Pi Compute Module 5/GPIO5: J9.6, Module1.34 (GPIO5)
/Rasperry Pi Compute Module 5/GPIO7: J9.7, Module1.37 (GPIO7)
/Rasperry Pi Compute Module 5/GPIO9: J9.8, Module1.40 (GPIO9)
/Rasperry Pi Compute Module 5/GPIO10: J9.9, Module1.44 (GPIO10)
/Rasperry Pi Compute Module 5/GPIO13: J9.4, Module1.28 (GPIO13)
/Rasperry Pi Compute Module 5/GPIO15: J9.15, Module1.51 (GPIO15)
/Rasperry Pi Compute Module 5/GPIO16: J9.5, Module1.29 (GPIO16)
/Rasperry Pi Compute Module 5/GPIO17: J9.14, Module1.50 (GPIO17)
/Rasperry Pi Compute Module 5/GPIO18: J9.13, Module1.49 (GPIO18)
/Rasperry Pi Compute Module 5/GPIO19: J9.2, Module1.26 (GPIO19)
/Rasperry Pi Compute Module 5/GPIO20: J9.3, Module1.27 (GPIO20)
/Rasperry Pi Compute Module 5/GPIO21: J9.1, Module1.25 (GPIO21)
/Rasperry Pi Compute Module 5/GPIO22: J9.10, Module1.46 (GPIO22)
/Rasperry Pi Compute Module 5/GPIO23: J9.11, Module1.47 (GPIO23)
/Rasperry Pi Compute Module 5/GPIO27: J9.12, Module1.48 (GPIO27)
/Rasperry Pi Compute Module 5/PMIC_ENABLE: J7.12, Module1.99 (PMIC_ENABLE)
/Rasperry Pi Compute Module 5/PWR_BUT: J7.14, Module1.92 (PWR_BUT)
/Rasperry Pi Compute Module 5/SYNC_OUT: J7.6, Module1.18 (Ethernet_SYNC_OUT(3.3v))
/Rasperry Pi Compute Module 5/USB2_N: J8.A7 (D-), J8.B7 (D-), Module1.103 (USB2_N)
/Rasperry Pi Compute Module 5/USB2_P: J8.A6 (D+), J8.B6 (D+), Module1.105 (USB2_P)
/Rasperry Pi Compute Module 5/USBOTG: J7.10, Module1.101 (USB_OTG_ID)
/Rasperry Pi Compute Module 5/nRPIBOOT: J7.2, Module1.93 (nRPIBOOT)
/VBUS: J8.A4 (VBUS), J8.A9 (VBUS), J8.B4 (VBUS), J8.B9 (VBUS)
GND: C1.2, C2.2, C3.2, C4.2, C5.2, C6.2, C7.2, C8.2, C9.2, C10.2, C11.2, C12.2, C13.2, C14.2, C15.2, C16.2, C17.2, C18.2, C19.2, C20.2, C21.2, C22.2, C23.2, C24.2, C25.2, C26.2, C27.2, C28.2, C30.2, C31.2, C32.2, C33.2, C34.2, C35.2, C36.2, C37.2, C38.2, IC1.3 (GND), IC1.8 (GND), IC2.3 (GND), IC2.8 (GND), IC3.19 (SHIELD), IC3.20 (SHIELD), IC4.47 (VREG_PGND), IC4.61 (GND), IC5.6 (VOUT-), IC5.7 (VOUT-), IC6.3, IC7.3, IC8.16 (SYNC), IC8.23 (PGND), IC8.24 (PGND), IC8.29 (AGND), IC9.3 (PGND), IC9.10 (PGND), IC9.11 (PGND), IC9.12 (AGND), IC9.15 (PGND), IC10.3 (GND), IC10.8 (GND), IC10.9 (GND), IC11.1 (SDO), IC11.6 (GNDIO), IC11.7 (GND), IC12.4 (VSS), J1.3, J2.2, J2.4, J2.5, J3.5, J4.5, J5.1, J5.4, J5.7, J5.10, J5.13, J5.16, J5.19, J6.1, J7.1, J7.3, J7.5, J7.7, J7.9, J7.11, J7.13, J8.A1 (GND), J8.A12 (GND), J8.B1 (GND), J8.B12 (GND), J8.SH (SHIELD), Module1.1 (GND), Module1.2 (GND), Module1.7 (GND), Module1.8 (GND), Module1.13 (GND), Module1.14 (GND), Module1.22 (GND), Module1.23 (GND), Module1.32 (GND), Module1.33 (GND), Module1.42 (GND), Module1.43 (GND), Module1.52 (GND), Module1.53 (GND), Module1.59 (GND), Module1.60 (GND), Module1.65 (GND), Module1.66 (GND), Module1.71 (GND), Module1.74 (GND), Module1.98 (GND), Module1.107 (GND), Module1.108 (GND), Module1.113 (GND), Module1.114 (GND), Module1.119 (GND), Module1.120 (GND), Module1.125 (GND), Module1.126 (GND), Module1.131 (GND), Module1.132 (GND), Module1.137 (GND), Module1.138 (GND), Module1.144 (GND), Module1.150 (GND), Module1.155 (GND), Module1.156 (GND), Module1.161 (GND), Module1.162 (GND), Module1.167 (GND), Module1.168 (GND), Module1.173 (GND), Module1.174 (GND), Module1.179 (GND), Module1.180 (GND), Module1.185 (GND), Module1.186 (GND), Module1.191 (GND), Module1.192 (GND), Module1.197 (GND), Module1.198 (GND), R14.2, R15.2, R21.2, R24.2, R27.2, Y1.2 (GND_1), Y1.4 (GND_2)
unnamed: C1.1, IC3.5 (MDCT), IC3.6 (MDCT)
unnamed: C29.2, IC8.25 (SW), IC8.26 (SW), L2.1
unnamed: D1.1 (A1), D2.5, D2.6, D2.7, D2.8, D3.5, D3.6, D3.7, D3.8, FB4.1
unnamed: D1.2 (A2), D4.1, D4.2, D4.3, D4.4, D5.1, D5.2, D5.3, D5.4, FB1.1
unnamed: FB1.2, FB2.1
unnamed: FB2.2, FB3.1
unnamed: FB4.2, FB5.1
unnamed: FB5.2, FB6.1
unnamed: IC4.24 (SWCLK), J2.1, R16.1
unnamed: IC4.25 (SWDIO), J2.3, R17.1
unnamed: IC4.9 (GPIO6), J3.1
unnamed: IC4.10 (GPIO7), J3.2
unnamed: IC4.12 (GPIO8), J3.3
unnamed: IC4.13 (GPIO9), J3.4
unnamed: IC4.29 (GPIO18), J4.1
unnamed: IC4.31 (GPIO19), J4.2
unnamed: IC4.32 (GPIO20), J4.3
unnamed: IC4.33 (GPIO21), J4.4
unnamed: J8.A5 (CC1), R15.1
unnamed: J8.B5 (CC2), R14.1
unnamed: IC8.5 (CLP), Q1.5 (D_1), Q1.6 (D_2), Q1.7 (D_3), Q1.8 (D_4), R1.1
unnamed: IC8.6 (INFET), Q1.4 (G)
unnamed: IC8.22 (BATFET), Q2.4 (G)
unnamed: IC8.21 (CSP), L2.2, Q2.1 (S_1), Q2.2 (S_2), Q2.3 (S_3), R20.1
unnamed: IC3.12 (LEDG_K), R3.1
unnamed: IC3.14 (LEDY_K), R2.1
unnamed: IC4.26 (RUN), R9.1, R11.2
unnamed: IC4.51 (USB_DM), R6.1
unnamed: IC4.52 (USB_DP), R7.1
unnamed: C17.1, IC4.46 (VREG_AVDD), R8.2
unnamed: IC4.60 (~QSPI_SS), R12.1, R13.2
unnamed: IC5.3 (TYP2-DET), IC6.2
unnamed: IC5.2 (TYP3-DET), IC7.2
unnamed: C21.1, FB6.2, IC5.9 (VIN+), IC6.1, IC7.1
unnamed: C24.1, FB3.2, IC5.1 (VIN-)
unnamed: C29.1, IC8.1 (BOOST)
unnamed: C31.1, IC8.8 (VCC2P5), IC8.17 (CELLS0), IC8.18 (CELLS1)
unnamed: C32.1, IC8.2 (INTVCC)
unnamed: IC8.10 (NTC), R26.2, R27.1
unnamed: IC8.9 (NTCBIAS), R26.1
unnamed: IC8.11 (RT), R21.1
unnamed: IC9.2 (EN), R22.2
unnamed: IC9.9 (FB), R24.1, R25.2
unnamed: IC9.6 (PGOOD), R23.1
unnamed: IC9.13 (V5V), R23.2
unnamed: C19.1, R10.1, Y1.3 (CRYSTAL_2)

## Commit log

2026-10-04 Add mainboard KiCad project
    Schematic sheets for the CM5 carrier with RP2354A thruster controller,
    project libraries, 3D models and a project footprint table so the
    CM5IO, BMI270 and SHT45 footprints resolve after cloning. KiCad backups,
    per-user view settings and third-party datasheets stay out of git.
    [10164227-1001a1rlf.stp, 471511051.stp, BM04B-SRSS-TB.STEP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]
2026-10-04 Document the board and credit the Raspberry Pi CM5 IO Board
    Parts of the design come from Raspberry Pi's CM5 IO Board KiCad files,
    which carry no open-source license. The README and NOTICE name the
    source, list the copied and adapted files and keep them outside the
    AGPL, together with the 3D model, SamacSys and KiCad library terms.
2026-10-05 Fix schematic connectivity and add flashing access
    The camera and Ethernet buses now connect across sheets: they use
    unnamed bus groups so the member nets keep their names. Ethernet pair 2
    negative is no longer tied to GND.
    The RP2354A core supply reaches the regulator output, and a 12 MHz
    crystal drives XIN/XOUT, which USB and the USB bootloader need. The
    CM5 gets GPIO_VREF on 3.3 V, the IO Board's boot and EEPROM jumper
    header, and a data-only USB-C port with 5.1 kOhm CC resistors for
    flashing the eMMC.
    [ABM8-272-T3.stp, cm5.kicad_sch, csi.kicad_sch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]
2026-10-05 Document flashing and the new components
    Describe the USB-C service port, the J7 jumper header and the crystal,
    explain how to flash the eMMC, and credit the CM5 IO Board circuits and
    SamacSys models the new parts come from.
2026-10-05 Assign footprints to all parts
    Connectors get footprints for the chosen hardware: JST GH for the ESC
    and pressure-sensor cables, XT30 for the battery and the GCT USB4105
    for the service port. The core regulator inductor and the SWD
    connector use the footprints from Raspberry Pi's RP2350A minimal
    design, which is MIT-licensed and credited in NOTICE.md. Every symbol
    pin now has a matching pad.
    [i2c_peripherals.kicad_sch, manafish.kicad_sch, rp2354a.kicad_sch]
2026-10-05 Update README with KiCad design link
    Added link to the latest KiCad design in the overview section.
2026-10-05 Small fixes
    [cm5.kicad_sch, csi.kicad_sch, ethernet.kicad_sch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]
2026-10-05 Update sensor connection, add 3d files
    [USB3stacked.STEP, i2c_peripherals.kicad_sch, manafish.kicad_pcb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]
2026-10-05 Add 3d files
    [AMASS_XT30PW-M.step, Ag5700_detailed.step, Ag5700_simplified.step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]
2026-10-05 Add rudimenatry poe module
    [AG5700.step, Ag5700_simplified.step, ethernet.kicad_sch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]
2026-10-05 Add the Silvertel library and limit the Ag5700 keep-out
    The sym-lib-table and fp-lib-table already pointed to the Silvertel
    library, but its files were not committed. Add the Ag5724-LPB symbol
    and the Ag5700-LPB footprint.
    The footprint's isolation keep-out covered every copper layer. With the
    module on the bottom of a 2-layer board, that also left a 36 mm strip
    with no copper on the top layer, between the CM5 connectors. The keep-out
    now covers the module's own layer and, as a second rule area, the inner
    layer next to it. A single area on both layers would not work: KiCad
    saves it on a 2-layer board as In1.Cu only, which drops the keep-out.
    U5 on the board is updated to match the library.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
    [manafish.kicad_pcb]
2026-10-06 Add PoE circuit
    [AG59800-LPB.step, V6K100DUHM3_H.stp, cm5.kicad_sch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]
2026-10-07 Add the LTC4162 charger library
    KiCad has no LTC4162 symbol, and its matching QFN-28 footprint points to
    a 3D model that does not exist. Add:
    - LTC4162-LAD symbol, drawn from the LTC4162-L datasheet (Rev A).
    - A copy of KiCad's QFN-28-1EP_4x5mm_P0.5mm_EP2.65x3.65mm_ThermalVias
    footprint with the 12 thermal vias drilled 0.3 mm, which this board's
    rules require. The original 0.2 mm drills give 12 DRC errors per part.
    - The missing 3D model, generated with KiCad's own model generator from
    KiCad's package data.
    Register both libraries, drop the duplicate V6K100DUHM3 row from
    fp-lib-table, and credit the new files and the SamacSys V6K100DUHM3
    files in NOTICE.md.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
    [QFN-28-1EP_4x5mm_P0.5mm_EP2.65x3.65mm.step]
2026-10-07 Finished power management circuit
    [FDMC8327L.stp, cm5.kicad_sch, manafish.kicad_pcb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]
2026-10-07 Fix I2C connection
    [manafish.kicad_sch]
2026-10-07 Fix the bridge diode and MOSFET libraries
    The SamacSys V6K100DUHM3 footprint had its two exposed cathode pads as
    separate pads 9-12 with no net. They touch the cathode pins, so DRC
    reported 24 shorts and 24 solder-mask bridges, and the paddles were left
    out of the copper. Number them like the cathode pins they belong to
    (8 and 5) and drop the hidden symbol pins 9-12. The four diodes on the
    board get the same pad numbers and their cathode nets.
    The FDMC86139P footprint used for Q1/Q2 had the same problem with its
    exposed drain pad (pad 9); it is now pad 5. Its origin is moved 0.4 mm
    to the centre of the package, so pick-and-place positions are right, and
    its 3D model path points to custom_co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
    [manafish.kicad_pcb, power_management.kicad_sch]
2026-10-08 Feed +3.3V into the power management sheet
    Replace the power management sheet's +5V output label with a +3.3V
    input and wire the new sheet pin on the root schematic. Ignore KiCad's
    local .history/ folder, which holds its own git repository.
    [manafish.kicad_sch, power_management.kicad_sch]
2026-10-09 Complete the power sheet and its part numbers
    Schematic fixes from the power review:
    - add the NTC bias network, PWR_FLAGs and the VOUTA capacitor C37
    - rename VBAT to VSYS
    Every power-sheet part now has Manufacturer, MPN, Mouser PN, Mouser and
    Datasheet fields. All Mouser numbers were checked on 2026-10-09.
    Part changes:
    - the 10 uF/50 V caps (C26, C28, C30, C33, C34) are all TDK
    C3225X7R1H106K250AC in 1210; C26 and C30 move from 1206 to 1210
    - C20 is a Nichicon UHW1V471MPD, same size as before; the Panasonic
    EEU-FR1V471 has a 37-week lead time, and the old Wurth number was 25 V
    - C29 and C37 use Murata's in-production GCM parts; C25 and C27 use KEMET
    - U6 and U7 are Lite-On LTV-817 (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
    [manafish.kicad_sch, power_management.kicad_sch]
2026-10-10 Lay out the 4-layer PCB
    Route the board on JLCPCB's JLC04161H-7628 stackup (4 layers, 1.6 mm,
    ENIG). It fits a 74 mm tube centred on its axis; the tightest part is the
    USB-C port J8, 1.8 mm from the wall. DRC gives 0 errors, 0 unconnected
    items and a clean schematic parity check. 21 advisory warnings remain on
    the 3 mm PoE isolation guide; the README lists them.
    Layout:
    - the PoE primary side keeps 2.0 mm from everything else on every layer,
    enforced by manafish.kicad_dru, with a primary-only island under U5's
    input half and inner-layer voids next to primary copper
    - 100 ohm (Ethernet, CSI) and 90 ohm (USB) pair classes over a solid In1
    ground; GND pours on all layers with stitching v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
    [JXF0-1012NL.step, ethernet.kicad_sch, manafish.kicad_pcb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]
2026-10-11 Add second camera, magnet load switch and schematic fixes
    - Second camera J11 on MIPI1: I2C on ID_SD/ID_SC with 2.2k pull-ups,
    power enable on GPIO14/15 (CAM1_GPIO0/1); both cameras take 3.3 V
    from CM5_3.3V
    - Magnet power switch: IC9 output is now +5V_AON, TPS22965 load switch
    IC15 drives +5V, J12 carries +5V_AON / MAG_ON / GND with R29
    pull-down; new TPS22965 symbol library
    - Power: 4 A TPSM53604, 8 mOhm input sense resistor, C39/C40 bulk caps,
    F1-F3 battery polyfuses; 5 V raised to 5.115 V (R24 2.43k, 0.5 %
    feedback resistors); 47 uF at the CM5 5 V pins
    - BMI270 on SPI and WSEN-PADS on I2C in serial_peripherals.kicad_sch
    - Breakout headers J9/J13 with 5 V, 3.3 V and GND
    - Refer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
    [cm5.kicad_sch, csi.kicad_sch, ethernet.kicad_sch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]
2026-10-11 Separate the supply pins on breakout headers J9 and J13
    Both headers now start with +5V, GND, GND, +3.3V (pins 1-4), so 5 V
    and 3.3 V only meet diagonally and each supply pin has GND beside it.
    The GPIOs that sat on pins 3/4 moved to the end of each header.
    [cm5.kicad_sch, manafish.kicad_sch, power_management.kicad_sch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]
2026-10-11 Redo the PCB layout: 70 x 90 mm, power section grouped, one-side reflow
    - Second camera connector J11 beside J5 on the top edge.
    - SHT45 on a slotted tongue (no pour, no vias, four tracks over a 2.5 mm
    bridge) for thermal decoupling.
    - All fine-pitch parts on top; the bottom holds only hand-solderable parts
    (IC5, connectors, 0603+ passives, fuses, electrolytics).
    - MagJack, PoE module, charger, 5 V buck and battery connector grouped in
    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
2026-10-11 Add switchable ESC power, vertical camera connectors and 3.3 V decoupling
    - ESC power switch on the root sheet:
    - Battery input J6 changes to XT60PW-M. New XT60PW-F J14 carries switched
    power to both ESCs.
    - Q3 (onsemi NTMFS5C404NLT1G, 40 V, 0.67 mOhm) is driven by the photovoltaic
    driver IC16 (Vishay VOM1271T) from RP2354A GPIO14 (ESC_PWR_EN) via R31.
    - Soft start C46/D6/R32 keeps Q3 in its SOA while the ESC capacitors charge.
    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
2026-10-12 Redo the PCB layout (rev 3): 70 x 109.2 mm, connectors on one side, 45° routing
    - All connectors on the top: cameras, USB-C and the magnet switch along the
    top edge, the rest at the bottom around the RJ45, which moves towards the
    centre line; C20 near the centre for the tube radius
    - Every part except the PoE module IC5 on the top (reflow one side)
    - 45-degree routing only, chamfers at least 1.5 x width, traces bundled to
    keep the planes whole
    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
2026-10-13 Add ngspice simulations of the ESC switch soft start
    esc_switch_turnon.cir compares the VOM1271 datasheet circuit (driver straight
    on Q3) with the C46/D6/R32/D7 soft start when switching on into the ESC input
    capacitors. esc_switch_unplug.cir shows why D7 is needed when the battery is
    unplugged. Q3 is a VDMOS model fitted to the NTMFS5C404NL datasheet.
    Claude-Session: https://claude.ai/code/session_01AhLYztcZikG9g81njGtEr1
2026-10-13 Add LCSC part numbers and links, fix J7 part number
    - Every part found on LCSC gets an "LCSC PN" (C-number) and an "LCSC" product
    link field, in the schematic and on the PCB footprints. Exact matches where
    LCSC lists the part; equivalents with the same specs where it does not or
    has no stock (C46, C26/C28/C30/C33/C34/C40, C29, C31, R6/R7, R21, R24,
    J3/J4, J7/J9/J13). Left empty: IC3, IC5 (not on LCSC), IC10, IC12
    (JLCPCB-only listings).
    - J7: the MPN 61301421121 is a 2.54 mm header, but the footprint is 1.27 mm.
    Now Wurth 62201421121 (WR-PHD 1.27 mm 2x7) with matching description,
    datasheet and Mouser fields.
    - Interactive HTML BOM in hardware/bom; KiCad project file re-saved.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
2026-11-09 Fix JLCPCB BOM and CPL, use JLCPCB Basic parts, rename LCSC field
    KiCad fields:
    - The LCSC part-number field is renamed from "LCSC PN" to "LCSC Part #",
    the name JLCPCB's KiCad guide uses. The rename covers every schematic sheet
    in the hierarchy, the PCB footprints, and the BOM preset in manafish.kicad_pro.
    The "LCSC" link field now points to each new code.
    - LCSC parts follow the selection made in JLCPCB's BOM tool
    (production/manafish_BOM_JLCPCB-JLCPCB Assembly Order (1).xls). Rule: use a
    JLCPCB Basic part where it does the job, otherwise keep the original part.
    - Basic parts taken from the selection:
    C1-C13,C16,C22,C23,C38,C43 C1525; C14,C15,C17 C23733; C18,C19 C1548;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
2026-11-12 Regenerate JLCPCB files, restore combined CM5 footprint, use Basic parts
    - Restore Raspberry Pi's combined CM5 footprint (2-unit symbol Module1), as on
    the CM5 IO Board reference design: keeps the two connectors locked at their
    spacing and ERC clean. Keep the 1.7 mm clearance on the mounting holes.
    - Swap the parts changed in the last layout to JLCPCB Basic parts: C29 C1532,
    C37 C307331, C47 C15850 (the X7R part had 4 in stock), R22/R23 C25741,
    R26/R27 C25744. R21 stays C4201041 (no Basic 0402 63.4k).
    - Fix swapped "LCSC Part #"/"LCSC" fields; jlc_export.py now also accepts an
    LCSC product URL in the field.
    - Regenerate Gerbers, BOM and CPL for the new layout, and the KiCad BOM exp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
2026-11-12 Remove dangling vias, update teardrops, clean up unused files
    - Remove the two dangling vias by R4/R5 (SCL1/SDA1); the F.Cu tracks now run
    into the resistor pads.
    - Regenerate teardrops and zone fills (78 teardrops were missing), and the
    JLCPCB Gerbers.
    - Remove unused library files: 9 CM5IO footprints from Raspberry Pi's IO-board
    library, the superseded Ag5700 PoE module (footprint, symbol, model, DRC
    rule), unused STEP models, the magnetic switch's unused footprints and its
    library entries pointing to another PC, and the old JLCPCB order export.
    - Update NOTICE.md and README.md: paths after the move to hardware/mainboard/,
    repository layout, and the files that remain.
    Co-Autho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
2026-11-12 Regenerate the interactive BOM
    The published ibom.html dated from 2026-10-14. It now shows the current
    layout and parts, with the same view settings, tracks, zones and nets; the
    LCSC column uses the renamed "LCSC Part #" field.
2026-11-12 Add a BOM for the magnetic switch PCB
    - Give every magnetic switch part manufacturer, MPN, LCSC and Mouser fields,
    in the schematic and on the board, using the LCSC parts that match the
    existing values (C1525, C25744, C25741, C11702, CD4013BM96 C13527,
    A1104LLHLT-T C459229). J12's "LCSC PN" field is now "LCSC Part #", as on
    the mainboard.
    - Export Magnetic Switch.csv and an interactive BOM (bom/ibom.html) for
    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
2026-11-12 Replace Y1 and R25, rename the CM5 connector placements
    - Y1: ABM8-272-T3 (C20625731) ran out; use Yajingxin TX322512M4DBDE2T
    (C5310728): 12 MHz, 10 pF, ESR 60 ohm, same pinout and pads, and the same
    JLCPCB footprint pad numbering, so no rotation change.
    - R25: JLCPCB Basic C25804 (10k 1%) instead of C706017 (0.5%). The notes on
    R24/R25 and the production README record the narrower +5V margin
    (about 4.98-5.25 V worst case).
    - BOM/CPL: the two CM5 connectors are Module1 and Module2 instead of
    Module1A/Module1B, which JLCPCB's BOM check read as several part types.
    - Refresh the stock notes, the KiCad BOM export and the interactive BOM.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
2026-11-12 Add teardrops to the magnetic switch PCB, regenerate its Gerbers
    Teardrops added in KiCad; the zones are refilled around them (the old GND
    fill was 0.13-0.20 mm from the new teardrops, under the 0.2 mm clearance).
    Gerbers and the interactive BOM regenerated. The .kicad_pro changes are
    KiCad's own resave.
2026-11-13 Add root CI workflows and a pre-commit config
    GitHub runs workflows only from the repository root, so the imported
    upstream CI never ran here. firmware-ci and software-ci repeat the
    quality gates from CLAUDE.md after a push; software-ci sets
    PICO_CONTROLLER_SOURCE so the C differential test runs instead of being
    skipped. software-image builds the SD image on an ARM runner and keeps
    it as a 7-day artifact. The pre-commit config runs ruff, ty and
    clang-format 19, the LLVM version of the firmware dev shell.
2026-11-13 Correct the hardware README and document the imported code
    The hardware corrections were checked against the netlist, the DRC
    report and the BOM: the BMI270 sits on the RP2354A's SPI1, the I2C
    table gains the LTC4162-LAD and the WSEN-PADS, J9 is a 2 x 10 header
    with a new pin order, Y1 is now the TX322512M4DBDE2T, SWD also reaches
    CM5 GPIO8/11, and DRC shows 4 PoE clearance errors and 3 starved
    thermals. The Ethernet LED colours are right; only the net names are
    swapped. Known issues are listed as next-revision notes.
    The README and NOTICE now cover the imported firmware/ and software/
    folders and their third-party parts, and both folders get a short
    mainboard fork note.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

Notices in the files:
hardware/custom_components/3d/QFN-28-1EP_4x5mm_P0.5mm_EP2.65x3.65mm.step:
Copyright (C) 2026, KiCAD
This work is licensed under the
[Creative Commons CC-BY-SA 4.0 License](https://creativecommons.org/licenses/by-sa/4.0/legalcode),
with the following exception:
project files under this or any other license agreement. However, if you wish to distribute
